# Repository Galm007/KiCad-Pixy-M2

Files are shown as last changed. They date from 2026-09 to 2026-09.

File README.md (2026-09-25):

# Pixy-M2 — Micromouse Controller PCB

A single-board controller for a micromouse robot. The board carries an
**ESP32-S3** module, two **DRV8231A** motor drivers with current regulation,
a **2S LiPo** power path with fusing, switching and UVLO, a **3.3 V buck**,
and connectors for four **VL53L0X** time-of-flight wall sensors, a **BNO085**
IMU and two **Pololu N20** gearmotors with encoders.

Designed in **KiCad 10**. 4-layer, 66 × 100 mm, fully placed and routed.

<p align="center">
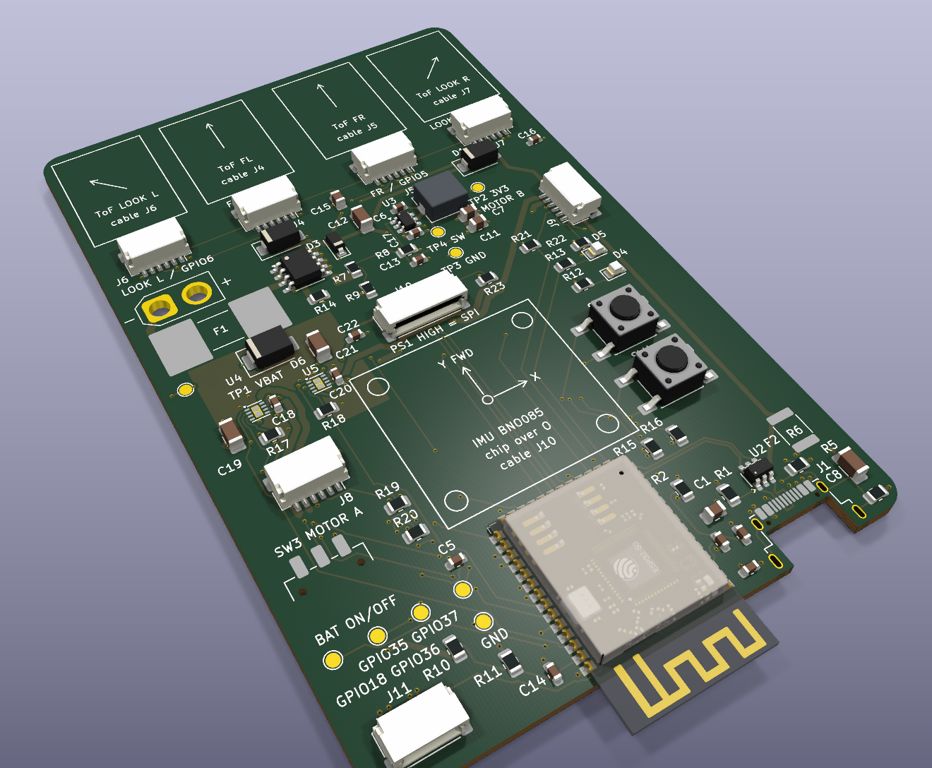
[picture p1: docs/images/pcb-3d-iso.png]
Pixy-M2 3D render, isometric view
  
</p>

| | |
|---|---|
| **MCU** | ESP32-S3-WROOM-1-**N16** (16 MB flash, no PSRAM), Wi-Fi/BLE, native USB |
| **Power in** | 2S LiPo (7.4 V nominal, 8.4 V full) via XT30, or USB-C 5 V |
| **Logic rail** | 3.3 V, AP63203 2 A synchronous buck |
| **Motor drive** | 2 × TI DRV8231A H-bridge, 1.00 A hardware current limit, per-motor current sense into the ADC |
| **Sensors** | 4 × VL53L0X ToF (I²C), BNO085 9-DoF IMU (SPI), 2 × 12 CPR quadrature encoders |
| **Protection** | 1500 A-breaking battery fuse, USB PPTC, 600 W TVS on the motor rail, USB ESD array, hardware UVLO |
| **PCB** | 66 × 100 mm, 4 layers, 1.6 mm, 78 footprints, 253 vias, ~2.4 m of track |
| **Status** | Schematic complete, ERC 0/0. Layout routed, DRC 0 violations / 0 unconnected / 0 parity. **Not yet fabricated.** |

---

## Contents

- [Board renders](#board-renders)
- [Schematic](#schematic)
- [System architecture](#system-architecture)
- [Design decisions](#design-decisions)
- [Pin and connector reference](#pin-and-connector-reference)
- [PCB layout](#pcb-layout)
- [Parts list](#parts-list)
- [Repository layout](#repository-layout)
- [Working with the project](#working-with-the-project)
- [Bring-up notes for firmware](#bring-up-notes-for-firmware)
- [Status and open items](#status-and-open-items)
- [License](#license)

---

## Board renders

The top of each image is the **front** of the robot: the four ToF sensor
mounts face the maze walls ahead, and the ESP32-S3 antenna overhangs the rear
edge.

<table>
  <tr>
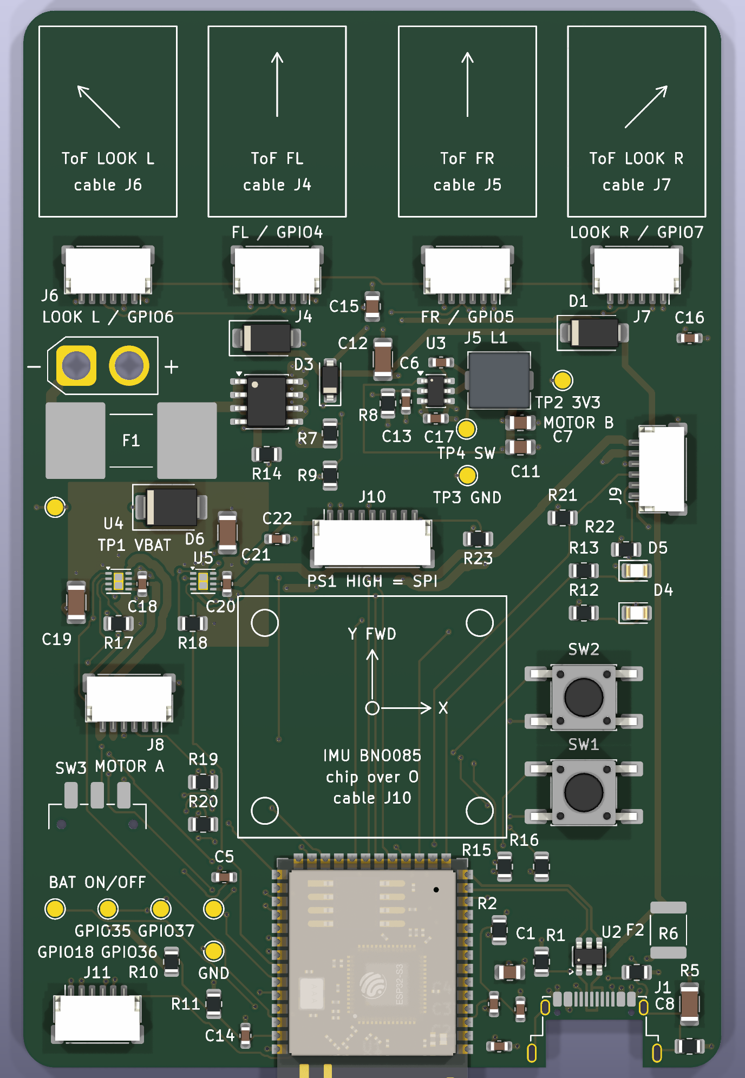
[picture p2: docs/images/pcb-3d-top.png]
Top side
    <td align="center"><br><b>Top</b></td>
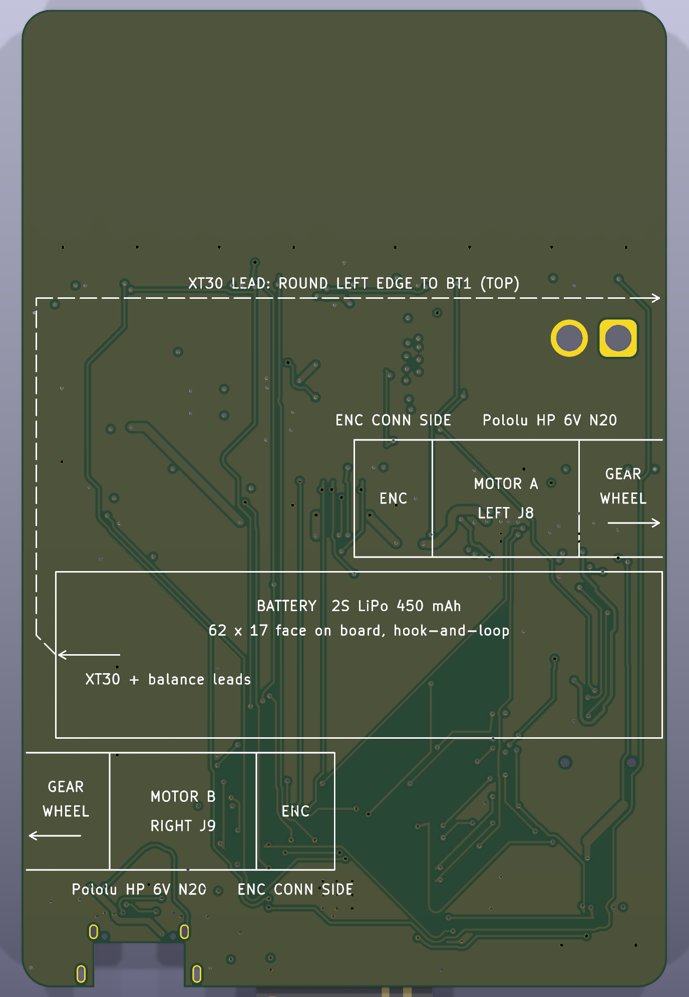
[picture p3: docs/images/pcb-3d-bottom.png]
Bottom side
    <td align="center"><br><b>Bottom</b> (mirrored)</td>
  </tr>
</table>

The silkscreen prints where each off-board part attaches:

- **Top:** the four ToF mounts with their aim arrows and the connector each
  cable plugs into, and the BNO085 breakout outline centred on the robot's
  rotation centre.
- **Bottom:** the two Pololu HP 6V gearmotors, with the gearbox face on the
  board edge and the shaft on the wheel axle. `ENC CONN SIDE` marks the face
  their encoder boards stand proud of, which must point outboard. Between the
  motors is the 2S battery's outline, with an arrow at the end its leads
  leave from and a dashed line for the lead's route round the left edge to
  BT1.

---

## Schematic

Single flat A3 sheet: [`Pixy-M2.kicad_sch`](Pixy-M2.kicad_sch).

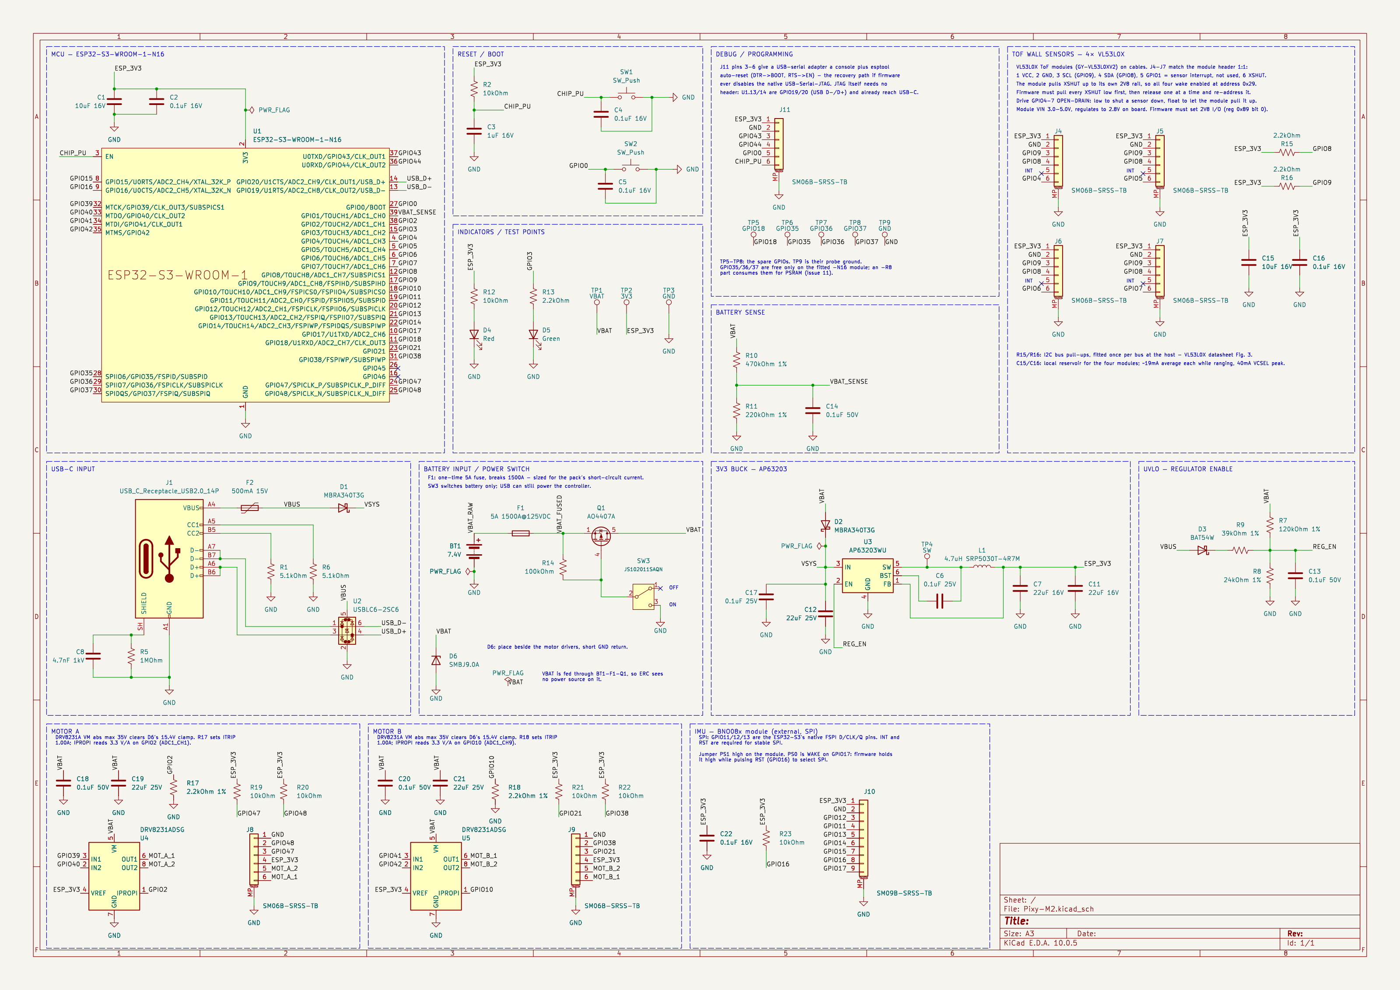
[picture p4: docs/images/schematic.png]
Schematic


---

## System architecture

```mermaid
flowchart LR
    BAT["2S LiPo<br/>XT30 (BT1)"] --> F1["F1<br/>5 A fuse<br/>1500 A break"]
    F1 --> Q1["Q1 P-FET<br/>switched by SW3"]
    Q1 -- VBAT --> DRV["U4 / U5<br/>DRV8231A ×2"]
    Q1 -- VBAT --> D6["D6 TVS<br/>SMBJ9.0A"]
    Q1 -- VBAT --> D2["D2<br/>Schottky"]
    USB["USB-C (J1)"] --> F2["F2<br/>500 mA PPTC"]
    F2 -- VBUS --> D1["D1<br/>Schottky"]
    D1 -- VSYS --> BUCK["U3 AP63203<br/>3.3 V buck"]
    D2 -- VSYS --> BUCK
    BUCK -- ESP_3V3 --> MCU["U1<br/>ESP32-S3"]
    BUCK -- ESP_3V3 --> PERIPH["ToF ×4, IMU,<br/>encoders"]
    DRV --> MOT["J8 / J9<br/>N20 motors + encoders"]
    MCU <-->|I²C| TOF["J4–J7<br/>VL53L0X ×4"]
    MCU <-->|SPI| IMU["J10<br/>BNO085"]
    MCU <-->|USB D±| USB
```

### Power path

```
 BT1+ ── F1 ── VBAT_FUSED ── Q1 (S→D) ── VBAT ──┬── D2 ──┐
                   │            │                ├── U4/U5 motor drivers
                  R14           G                ├── R7/R8 UVLO divider
                   └────────────┤                ├── R10/R11 battery sense
                           SW3 (gate only)       └── D6 TVS to GND
                                                          ├── VSYS ── U3 buck ── ESP_3V3
 J1 VBUS ── F2 ── VBUS ── D1 ─────────────────────────────┘
                   ├── D3/R9 USB enable path
                   └── U2 ESD clamp reference
```

- **`VBAT`** is the switched, fused motor rail. Motor current does **not** pass
  through D2. D2 feeds only the buck input.
- **`VSYS`** is the diode-OR of battery and USB. It reaches **~8.1 V** on a
  full pack.
- **`ESP_3V3`** feeds the module, the four ToF sensors, the IMU, the encoders,
  the LEDs and the drivers' `VREF` pins.
- **USB alone runs the controller** with SW3 off. That makes bench work and
  flashing possible without a pack. There is no on-board charger; charge the
  pack separately.

---

## Design decisions

The full reasoning, including rejected alternatives and the measurements behind
each change, lives in [`CLAUDE.md`](CLAUDE.md). This section covers the main
choices.

### One board, no daughterboard

An earlier version put the motors, drivers and IMU on a daughterboard that
mated through two 22-pin headers. Those headers were the heaviest and tallest
parts after the module, and they carried motor return current through eight
ground pins. The design now puts everything on one 4-layer board. Motor
return current flows in a solid ground plane, and the robot loses the mass and
height of the headers. The headers were deleted only once every GPIO they
carried ended on a real part.

### Motor driver: TI DRV8231A

The driver has to survive what the TVS lets through, not just the 8.4 V pack.
D6 clamps `VBAT` at up to **15.4 V**, and that ruled out the usual micromouse
parts:

| Part | VM abs max | Verdict |
|---|---:|---|
| DRV8833 | 11.8 V | below the clamp: rejected |
| TB6612FNG | 15.0 V | below the clamp: rejected |
| DRV8874 / DRV8876 | 40 V | good, but no stock KiCad symbol |
| **DRV8231A** | **35 V** | **fitted**, 2.3× the clamp |

The DRV8231A also:

- runs down to **4.5 V**, which covers the whole usable pack range;
- has **internal 100 kΩ pulldowns on IN1/IN2**, so both motors stay off while
  the ESP32's GPIOs float at reset;
- needs no nSLEEP or nFAULT pin, which saves GPIOs;
- has **integrated current regulation and an `IPROPI` sense output**.

### Current limit: 1.00 A, set by the connector

```
ITRIP = VREF / (AIPROPI × RIPROPI) = 3.3 V / (1500 µA/A × 2.2 kΩ) = 1.00 A
```

J8/J9 use JST SH connectors so Pololu's own encoder cable plugs in 1:1. SH
contacts and that cable are rated **1 A**, so R17/R18 hold the limit there.
The limit still gives ~63 % of the motor's 6 V stall torque. It also bounds the
driver's dissipation: an unregulated stall at 8.4 V would draw ~1.9 A and put
the 2 × 2 mm WSON into thermal shutdown. `IPROPI` reads 3.3 V/A on an ADC1 pin
for each motor, so firmware can detect a stall and cut drive long before the
fuse matters.

### Battery fuse: one-time, 1500 A breaking

The chosen pack is a 2S 450 mAh 100C LiPo. Its estimated dead-short current is
**200–400 A**. The original 3 A PPTC could only break 40 A, so it was replaced
with a **Littelfuse 0885005.DR**: 5 A fast-acting, 1500 A breaking at
125 VDC. Normal worst-case load is ~2.4 A: both motors at the limit plus the
buck. Slow overload protection is now the job of the driver current limit and
firmware stall detection. F1 only opens on a real fault.

### Hardware undervoltage lockout

The buck's `EN` pin has a built-in comparator with switched hysteresis. A 1 %
divider (R7/R8) on `VBAT` sets it to:

| | Pack voltage | Per cell |
|---|---:|---:|
| Turn on | 6.90 V | 3.45 V |
| Turn off | 5.94 V | 2.97 V |

A second path from `VBUS` (D3 + R9) holds `EN` high on USB alone, so the board
runs with no pack fitted. D3 is required. Without it, R9 becomes a pull-down
whenever a USB cable from an unpowered host is plugged in, and the board will
not start on battery. Firmware still does the accurate low-voltage cutoff; the
hardware UVLO is the backstop for when firmware is not running.

### Battery sense without a gate FET

`VBAT` → 470 kΩ / 220 kΩ → GPIO1 (ADC1_CH0), with a 100 nF reservoir cap.

- The divider draws 12 µA, well under the 58 µA of the UVLO divider, which
  cannot be gated. A gate FET would save almost nothing.
- A low-side gate would have been harmful: the sense node floats up into the
  GPIO clamp.
- A full-pack reading sits at 2.68 V. Even a badly overcharged 9.5 V pack reads
  3.03 V, still inside the ADC's range.
- Both dividers are downstream of Q1, so SW3 OFF removes their drain on the
  pack.

### Buck converter

- The **AP63203WU** is a fixed 3.3 V part, so it needs no feedback divider.
- **L1 is a Bourns SRP5030T-4R7M** (Isat 6 A, 53 mΩ). It replaced an 0805
  inductor that would have saturated at a few hundred mA.
- **C17 straddles the package under U3**, across IN and GND, which is the
  tightest input loop the pinout allows. C12 (22 µF 25 V 1206) is the bulk. It
  keeps ~11–13 µF at 8.4 V bias, which meets the datasheet's 10 µF effective
  input capacitance.
- **The switch node is 3.57 mm² of top copper with no vias.** TP4 hangs off it
  as a short stub.

### OR-ing diodes

D1 and D2 are the same **onsemi MBRA340T3G** (40 V, 3 A, SMA). D2 carries
only the buck's input, ~0.43 A worst case, so an ideal-diode controller is not
worth it. The 40 V rating covers the 15.4 V TVS clamp reaching `VSYS`.

### IMU on SPI, not I²C

The BNO085 could have shared the ToF I²C bus on throughput alone. It was put
on its own SPI bus for **latency**: an IMU interrupt that arrives mid-way
through a ToF read would wait up to ~150 µs, which is 15 % of a 1 kHz control
period. SCK, MOSI and MISO are on the ESP32-S3's native FSPI pins, so they go
through the IO MUX rather than the GPIO matrix. INT and RST are wired because
the BNO08x needs both for stable SPI. WAKE shares a pin with PS0 on the module.

### Four ToF sensors on one I²C bus

Every VL53L0X powers up at address `0x29`, and the address is volatile. Each
sensor therefore gets its own XSHUT line (GPIO4–7), so firmware can release the
sensors one at a time and re-address them. R15/R16 (2.2 kΩ) are the only bus
pull-ups, placed near the host, as the datasheet recommends. J4–J7 use the
GY-VL53L0XV2 module's own header order, so the cable is a straight 1:1 loom.

### USB

- **Series resistors deleted.** The ESP32-S3 PHY is impedance-matched, and the
  extra pads would have broken the differential pair beside the connector.
- **U2 (USBLC6-2SC6) is turned 90°** so its flow-through pins face J1 and U1.
  The pair then runs J1 → U2 → U1 entirely on the top layer with no vias.
- **Pair geometry is 0.25 mm trace / 0.15 mm gap.** A 2-D field solver
  ([`tools/impedance/zdiff.py`](tools/impedance/zdiff.py)) gives 88–94 Ω on a
  JLC04161H-7628 stackup.
- **No JTAG header.** The built-in USB-Serial-JTAG over USB-C already provides
  flashing, console and debugging.

### Strapping pins

GPIO45 and GPIO46 carry explicit no-connect flags. Driving GPIO45 high at reset
sets the flash rail to 1.8 V and the board will not boot. GPIO46 high with
GPIO0 low is an invalid boot combination. GPIO3 is the safe one of the three,
and drives the green status LED active-high, so its reset state stays low.

### Capacitor ratings

Every capacitor's voltage rating is in its Value field, so it shows on the
schematic. Two are worth pointing out:

- **C8** (USB shield) is **4.7 nF 1 kV in 1206**. An 8 kV ESD contact
  discharge puts ~250 V across it.
- **C19/C21** (motor bulk) are **22 µF 25 V** because of the 15.4 V TVS clamp.

---

## Pin and connector reference

### GPIO allocation

All 23 GPIOs left free after the core functions are used; four are spares on
test pads.

| Function | GPIO |
|---|---|
| USB D− / D+ | 19 / 20 |
| Boot button (SW2), also J11 | 0 |
| Battery sense (ADC1_CH0) | 1 |
| Status LED (green, active high) | 3 |
| ToF XSHUT 1–4 (J4–J7) | 4, 5, 6, 7 |
| I²C SDA / SCL (ToF bus) | 8 / 9 |
| Motor A IN1 / IN2 | 39 / 40 |
| Motor B IN1 / IN2 | 41 / 42 |
| Motor A / B current sense (IPROPI, ADC1) | 2 / 10 |
| Encoder A: OUT A / OUT B | 47 / 48 |
| Encoder B: OUT A / OUT B | 21 / 38 |
| IMU SPI SCK / MOSI / MISO / CS | 12 / 11 / 13 / 14 |
| IMU INT / RST / WAKE (PS0) | 15 / 16 / 17 |
| Debug UART0 TX / RX (J11) | 43 / 44 |
| Spare, on TP5–TP8 | 18, 35, 36, 37 |
| Strapping, deliberately no-connect | 45, 46 |

### Connectors

All the signal connectors are **JST SH 1.0 mm side-entry**.

**J4–J7: VL53L0X ToF sensors** (`SM06B-SRSS-TB`, GY-VL53L0XV2 header order)

| Pin | 1 | 2 | 3 | 4 | 5 | 6 |
|---|---|---|---|---|---|---|
| Signal | **VCC 3.3 V** | GND | SCL | SDA | INT (NC) | XSHUT |

> ⚠️ Pin 1 is **VCC**, not GND. A cable built "the usual way round" puts
> 3.3 V on the sensor's ground.

| Connector | Position | XSHUT |
|---|---|---|
| J4 | Front left (FL) | GPIO4 |
| J5 | Front right (FR) | GPIO5 |
| J6 | Look-ahead left, 45° | GPIO6 |
| J7 | Look-ahead right, 45° | GPIO7 |

**J8 / J9: motor + encoder** (`SM06B-SRSS-TB`, Pololu 12 CPR encoder order)

| Pin | 1 | 2 | 3 | 4 | 5 | 6 | MP |
|---|---|---|---|---|---|---|---|
| Signal | GND | OUT B | OUT A | VCC 3.3 V | M2 | M1 | GND |
| Pololu wire | green | white | yellow | blue | black | red | — |

J8 is motor A (left) and J9 is motor B (right). Use Pololu's straight SH–SH
encoder cable (#4765–#4769). R19–R22 pull the encoder outputs up to 3.3 V.

**J10: BNO085 IMU** (`SM09B-SRSS-TB`)

| Pin | 1 | 2 | 3 | 4 | 5 | 6 | 7 | 8 | 9 |
|---|---|---|---|---|---|---|---|---|---|
| Signal | VIN 3.3 V | GND | SCK | MOSI | MISO | CS | INT | RST | WAKE / PS0 |

> ⚠️ Jumper **PS1 high** on the module. Stock BNO08x breakouts ship in I²C mode
> and will not answer on SPI until it is changed.

**J11: debug / recovery** (`SM06B-SRSS-TB`)

| Pin | 1 | 2 | 3 | 4 | 5 | 6 |
|---|---|---|---|---|---|---|
| Signal | 3V3 (reference only) | GND | U0TXD | U0RXD | GPIO0 (BOOT) | CHIP_PU (EN) |

Pins 3–6 are an esptool auto-reset interface for a USB-UART adapter: DTR →
BOOT, RTS → EN. It is the way back in if firmware ever disables the native USB.

**Other**

| Ref | Part | Purpose |
|---|---|---|
| J1 | Amphenol 12401948E412A USB-C | Power, flashing, console, JTAG |
| BT1 | XT30U-M | 2S LiPo input |
| SW1 / SW2 | Tactile | Reset / Boot |
| SW3 | C&K JS102011SAQN slide | Battery ON/OFF (gate control only) |
| D4 / D5 | Red / green LED | Power (always on) / status (GPIO3) |
| TP1–TP4 | Test pads | VBAT, 3V3, GND, SW node |
| TP5–TP9 | Test pads | Spare GPIO18/35/36/37, probe GND |

---

## PCB layout

### Stackup

4 layers, 1.6 mm, designed for **JLC04161H-7628** (~0.2 mm L1–L2 prepreg).

| Layer | Use |
|---|---|
| **L1** F.Cu | Components, USB pair, buck switch node, motor-driver power loops, ground pour around the motor region |
| **L2** In1.Cu | **Solid, unbroken GND plane.** No signals, no splits. |
| **L3** In2.Cu | `ESP_3V3` pour plus a separate `VBAT` island under the motor region |
| **L4** B.Cu | Secondary routing plus a GND pour stitched to L2 |

The ground plane is never split. Noise is controlled by **placement**
instead. The motor drivers, the bulk capacitors, D6 and the battery entry
share the left-hand region. The MCU, ADC nodes and I²C sit away from it.

<p align="center">
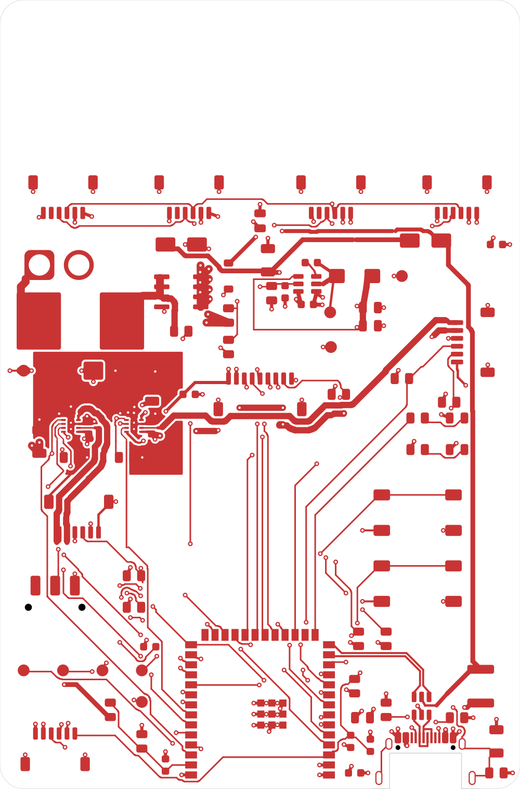
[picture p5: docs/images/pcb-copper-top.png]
Top copper layer
  <br>
  <em>Top copper (F.Cu). The 0.8 mm motor trunks, the 1.0 mm battery path and the motor-region ground pour are on the left.</em>
</p>

### Layout highlights

- **Motor outputs** are 0.8 mm trunks. The only narrower copper is inside
  each driver's own pin field, and a custom DRC rule enforces that. Each pair
  runs together to its connector: the loop areas are **23.9 mm²** (A) and
  **9.8 mm²** (B).
- **Driver thermal pads** each have two filled-and-capped in-pad vias
  (IPC-4761 type VII) plus four more nearby. Only two fit a 0.9 × 1.6 mm pad
  under the hole-to-hole rule.
- **VM bypass caps** sit 1.33 mm from each driver's VM pin, across VM and GND.
  The loop closes in top copper with no plane hop.
- **Antenna keep-out**: the module's antenna overhangs the rear edge, with an
  all-layer copper keep-out defined as a board rule area.
- **Rules are encoded, not just followed.** Netclasses and
  [`Pixy-M2.kicad_dru`](Pixy-M2.kicad_dru) enforce:
  - motor trunk width;
  - USB width, layer and coupling;
  - power and battery path widths;
  - a 0.2 mm signal floor;
  - clearance floors keeping `REG_EN`, `VBAT_SENSE` and the IPROPI lines away
    from motor and switching copper.

  Each rule was tested by breaking a copy of the board and checking that DRC
  fired.

The board was routed by a purpose-written A* grid router
([`tools/autoroute/`](tools/autoroute/)) and then reworked in stages, each
driven by a design review. Every stage is scripted and reproducible. The review
findings and the evidence for each fix (DRC reports, measurements,
before/after images) are under [`layout/`](layout/).

---

## Parts list

Parts for **one robot**, taken from **[`BOM.md`](BOM.md)**. BOM.md also has
each part's status, the cable wiring, the mechanical parts and the tools. The
shopping list below has one line per part to buy.

### Shopping list

Quantities are exact, with no spares except the crimp contacts. Where BOM.md
lets one part fill several positions, the list merges them: one 0.1 µF 50 V
part covers all eleven 0.1 µF positions, and every resistor is bought at 1 %.
R7–R11 and R17/R18 must stay 1 %: they set the UVLO thresholds, the
battery-sense ratio and the motor current limit.

| Qty | Part | For |
|---:|---|---|
| 1 | Espressif **ESP32-S3-WROOM-1-N16** | U1. N16 only, not an `-R8` variant |
| 2 | TI **DRV8231ADSGR** | U4, U5 |
| 1 | Diodes Inc **AP63203WU-7** | U3. Fixed 3.3 V, not the AP63200 |
| 1 | ST **USBLC6-2SC6** | U2 |
| 1 | AOS **AO4407A** | Q1. Not the IRF7404 the symbol names |
| 2 | onsemi **MBRA340T3G** | D1, D2 |
| 1 | Vishay **BAT54W-E3-08** (SOD-123) | D3. Nexperia's BAT54W is SOT-323 and won't fit |
| 1 | Vishay **SMBJ9.0A-E3/52** | D6 |
| 1 | Red LED, high-efficiency, 0805 | D4. Must be visibly lit at ~150 µA |
| 1 | Green LED, 0805 | D5 |
| 1 | Bourns **SRP5030T-4R7M** | L1 |
| 1 | Littelfuse **0885005.DR** | F1 |
| 1 | Bourns **MF-MSMF050-2** | F2 |
| 1 | C&K **JS102011SAQN** | SW3 |
| 2 | E-Switch **TL3301NF160QG** | SW1, SW2 |
| 1 | Amphenol **12401948E412A** | J1 |
| 1 | AMASS **XT30U-M** | BT1 |
| 7 | JST **SM06B-SRSS-TB(LF)(SN)** | J4–J9, J11 |
| 1 | JST **SM09B-SRSS-TB(LF)(SN)** | J10 |
| 11 | 0.1 µF 50 V X7R, 0603 | C2, C4–C6, C13, C14, C16–C18, C20, C22 |
| 1 | 1 µF 16 V X7R, 0603 | C3 |
| 2 | 10 µF 16 V X5R/X7R, 0805 | C1, C15 |
| 2 | 22 µF 16 V X5R/X7R, 0805 | C7, C11 |
| 3 | 22 µF 25 V X5R/X7R, 1206 | C12, C19, C21 |
| 1 | 4.7 nF 1 kV, 1206 | C8 |
| 7 | 10 kΩ 1 %, 0805 | R2, R12, R19–R23 |
| 5 | 2.2 kΩ 1 %, 0805 | R13, R15–R18 |
| 2 | 5.1 kΩ 1 %, 0805 | R1, R6 |
| 1 | 24 kΩ 1 %, 0805 | R8 |
| 1 | 39 kΩ 1 %, 0805 | R9 |
| 1 | 100 kΩ 1 %, 0805 | R14 |
| 1 | 120 kΩ 1 %, 0805 | R7 |
| 1 | 220 kΩ 1 %, 0805 | R11 |
| 1 | 470 kΩ 1 %, 0805 | R10 |
| 1 | 1 MΩ 1 %, 0805 | R5 |
| 1 | 4-layer PCB, 1.6 mm, 66 × 100 mm | Order with the [fabrication options](#pcb-fabrication-options) below |
| 1 | SMT stencil | Optional, but hard to do without for the WSON parts |
| 4 | **GY-VL53L0XV2** ToF module (`HW-842`) | Wall sensors on J4–J7 |
| 1 | Adafruit **BNO085** breakout, #4754 | IMU on J10 |
| 2 | Pololu **Micro Metal Gearmotor HP 6V with 12 CPR encoder** (#5153–#5165) | J8, J9. Gear ratio not chosen yet; use the same for both |
| 2 | Pololu **JST SH encoder cable**, female–female (#4765–#4769, 10–63 cm) | Motors to J8, J9 |
| 1 | OVONIC **2S 450 mAh 100C LiPo, XT30** | BT1. The Amazon listing (B0D2KT723L) is a 4-pack |
| 5 | JST **SHR-06V-S-B** housing | Four ToF cables and the optional debug lead |
| 1 | JST **SHR-09V-S-B** housing | IMU cable |
| ~80 | JST **SSH-003T-P0.2-H** crimp contact | 39 are used; hand crimping wastes some |
| — | 28–32 AWG wire | ToF, IMU and debug cables |

Not listed here:

- **Mechanical parts.** Wheels, motor brackets, drivetrain and sensor brackets
  are not designed yet.
- **Tools.** A 2S balance charger (XT30, JST-XH), a JST SH crimp tool, solder
  paste with hot air or reflow, and a 3.3 V USB-UART adapter for J11.

Both are in BOM.md, sections E and F.

### PCB fabrication options

- 4-layer, 1.6 mm, JLC04161H-7628 or equivalent.
- **Impedance control** on USB D+/D− (90 Ω differential), or confirm the
  geometry with the fab's calculator.
- **Via fill and cap (IPC-4761 type VII)** for the four thermal vias under
  U4/U5. The requirement is noted on `Dwgs.User`. Tenting is not a substitute.

---

## Repository layout

```
Pixy-M2.kicad_pro / .kicad_sch / .kicad_pcb   KiCad 10 project
Pixy-M2.kicad_dru                             custom DRC rules
Pixy-M2.pretty/                               project footprint library (U1 with antenna overhang)
fp-lib-table                                  registers the project library
BOM.md                                        full bill of materials
CLAUDE.md                                     full design notes: every decision, issue and measurement
REVIEW.md                                     layout design review
docs/images/                                  renders used in this README
layout/                                       placement notes, review evidence, DRC/ERC reports per fix
tools/autoroute/                              the grid router and scripted rework stages
tools/impedance/zdiff.py                      2-D field solver for the USB differential pair
DS_vl53l0x.pdf                                VL53L0X datasheet
```

`USB_C_Receptacle_Amazon.kicad_mod` in the root is **not used** by the board.
J1 uses the stock `Connector_USB:USB_C_Receptacle_Amphenol_12401948E412A`.

---

## Working with the project

Open `Pixy-M2.kicad_pro` in **KiCad 10**. The project library `Pixy-M2.pretty`
is registered through `fp-lib-table`. The Espressif footprint library
(`PCM_Espressif`) is only needed if you want to compare U1 against the stock
footprint.

### Checks

```sh
# Electrical rules
kicad-cli sch erc -o erc.rpt Pixy-M2.kicad_sch

# Design rules, with zone refill and schematic parity
kicad-cli pcb drc --schematic-parity --refill-zones --format json -o drc.json Pixy-M2.kicad_pcb

# Netlist, to diff after any schematic edit
kicad-cli sch export netlist --format kicadsexpr -o after.net Pixy-M2.kicad_sch
```

Current results: **ERC 0 errors / 0 warnings; DRC 0 violations, 0 unconnected
items, 0 schematic-parity issues.**

Always refill zones before DRC. Without a refill, every plane-connected pad
shows up as unconnected.

### Things that will silently break the design

- **Do not "Update Symbols from Library" on U4/U5.** The stock
  `Driver_Motor:DRV8231ADSG` symbol types OUT2 as `power_in`. The copy cached in
  this schematic fixes it to `output`. Updating reverts the fix and brings back
  two ERC errors.
- **Do not "Update Footprint from Library" on U1** back to `PCM_Espressif`.
  That restores antenna silkscreen that prints off the board edge.
- **Do not rotate U2 back** without re-routing the USB pair.
- **Keep "Signal minimum width" as the first rule in `Pixy-M2.kicad_dru`.**
  When two rules set the same constraint, the later one wins. Moving this rule
  below the motor, USB or power rules relaxes them to 0.2 mm.
- **Close KiCad before editing the files on disk.** A `~Pixy-M2.*.lck` file
  means the GUI has the project open, and whichever side saves last wins.

### Generating fabrication files

Gerbers, drill files and placement files are generated outputs and are
git-ignored. Export them from the PCB editor, or run:

```sh
kicad-cli pcb export gerbers -o gerbers/ Pixy-M2.kicad_pcb
kicad-cli pcb export drill   -o gerbers/ Pixy-M2.kicad_pcb
kicad-cli pcb export pos     -o gerbers/Pixy-M2-pos.csv Pixy-M2.kicad_pcb
```

---

## Bring-up notes for firmware

- **ToF sensors all wake at `0x29`.** GPIO4–7 float at reset and the modules
  pull XSHUT up, so all four sensors come up enabled at once. Firmware should
  first **drive all four XSHUT lines low**, then release one at a time and
  write a new address to register `0x8A`. The addresses are lost at every
  power cycle.
- **Drive XSHUT open-drain** (`GPIO_MODE_OUTPUT_OD`), not push-pull. The
  module's XSHUT sits on a 2.8 V rail.
- **Leave the VL53L0X driver's 2V8 I/O mode on.** It is the default in both ST's
  API and Pololu's library.
- **Motors sleep when IN1 = IN2 = 0.** The drivers' internal pulldowns keep
  them off until firmware drives the pins.
- **Cap motor PWM at ~71 % duty.** The N20s are 6 V motors on an 8.4 V pack;
  71 % gives a 6 V equivalent on a full pack.
- **Use IPROPI for stall detection** (GPIO2 / GPIO10, 3.3 V/A). The ADC clips
  at ~0.94 A, just under the 1.00 A limit, so a stall reads as full scale.
- **Battery sense:** use `ADC_ATTEN_DB_12`. Scale by 690/220 and calibrate once
  against a meter reading at TP1. Allow ~50 ms after a step change (15 ms RC),
  and average over whole PWM periods.
- **With USB connected, the hardware UVLO is bypassed.** Firmware must cut off
  a low pack itself in that case.
- **Keep ADC reads on ADC1.** Every analog input already is, because ADC2 is
  unusable while Wi-Fi is active.
- **Status LED:** drive GPIO3 **high** to light it.

---

## Status and open items

**Done:** schematic, placement, routing, the design-review rework, the DRC
rule set and the silkscreen assembly marks. The last unmet layout rule, R8 and
C13 beside U3's EN pin, was closed on 2026-09-24
([`layout/reg-en/`](layout/reg-en/README.md)). No `REG_EN` copper is under U3
any more. Its closest approach to the switch node is now U3's own 0.95 mm pin
gap; it was 0.40 mm.

**Open before or during first fabrication:**

- [ ] **Mechanical design.** The drivetrain, wheel mounts and sensor brackets
      are not designed. The PCB has **no mounting holes** yet. The battery
      goes across the underside between the motors (2026-09-24), so the motor
      brackets may only fasten on the motors' outboard sides. The pack's lead
      needs about 13 cm to reach BT1; see `BOM.md`, "Battery".
- [ ] **Motor gear ratio.** Pick one for both motors. 12 CPR before gearing is
      low, so check that the ratio gives enough encoder edges for the control
      loop.
- [ ] **Current budget on real hardware.** Measure F1 temperature and U4/U5
      thermals during hard acceleration and stalls.
- [ ] **USB impedance.** Confirm 0.25 / 0.15 mm with the fab's calculator, or
      order impedance control.
- [ ] **IPROPI traces** pass 0.53 mm from motor copper. Validate on hardware.
- [ ] **Antenna performance** with the battery, motors and brackets fitted.

See [`CLAUDE.md`](CLAUDE.md) for each item's history and the reasoning behind
it.

---

## License

The design files, scripts and documentation in this repository are released
under the [MIT License](LICENSE).

Third-party material keeps its own terms:

- `DS_vl53l0x.pdf` is STMicroelectronics' datasheet, included for reference.
- `Pixy-M2.pretty/ESP32-S3-WROOM-1_AntennaOverhang.kicad_mod` is derived from
  Espressif's KiCad footprint library and remains under that library's license.

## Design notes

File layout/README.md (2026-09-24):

# Pixy-M2 initial placement — 2026-09-21

This is an **unrouted, provisional chassis layout**, not fabrication-ready mechanical design.

## Geometry and reservations

The PCB is 66 × 100 mm with R3 corners and a single closed perimeter. J1's stock mid-mount USB-C footprint requires a rear-edge notch; its Edge.Cuts geometry is integrated into the perimeter. There are no additional mounting holes or drivetrain cutouts. Existing connector locating holes remain part of their assigned footprints.

Coordinates in `placement.json` are millimetres from the board's front-left corner, +X right and +Y rear; the KiCad origin for this corner is (100, 60) mm. Angles follow KiCad footprint rotation conventions. The front is at the top of the preview.

| Reservation | Position relative to PCB front-left | Size / meaning |
|---|---|---|
| Complete width allowance | X = −12…78 | 90 mm including wheels, gears, brackets and cable protrusions |
| Side drive lanes | X = −12…0 and 66…78 | 12 mm each; illustrative 8 mm tire + 4 mm gear/clearance allocation |
| Wheel axes | Y = 50 and 82 | Ø30 mm wheels, 32 mm wheelbase |
| Left underside motor | X = 0…38, Y = 40…56 | 38 × 16 × 16 mm including encoder/cable allowance; shaft toward left. *Was Y = 44…60 until 2026-09-24: the 4 mm encoder allowance now faces outboard (forward)* |
| Right underside motor | X = 28…66, Y = 76…92 | 38 × 16 × 16 mm including encoder/cable allowance; shaft toward right. *Was Y = 72…88 until 2026-09-24: the allowance now faces outboard (rearward)* |
| Underside battery | X = 0.5…62.5, Y = 57.5…74.5, between the motors; rule area to X = 66 for the lead exit | 62 × 17 × 14 mm (OVONIC 2S 450 mAh, maker's envelope), wide face on the board, leads at the +X end. *Was X = 13…53, Y = 5…35 (40 × 30 × 15) until 2026-09-24* |
| Top-side IMU | X = 20.5…45.5, Y = 53.5…78.5 | 25 × 25 mm around nominal rotation centre (33, 66) |
| Four top sensor mounts | X = 1…15, 17…31, 35…49, 51…65; Y = 1…20 | 14 × 19 mm provisional mount/module envelope each |
| Antenna | Rear-centre; module reaches Y = 105.75 | Overhang, all-layer copper keepout and additional no-metal drawing |

`Dwgs.User` shows top reservations, drive lanes, wheels, axes, aim directions and dimensions. `User.1` shows underside body envelopes. `User.2` shows provisional attachment bands and RF clearance. These bands are reserved space, not final bolt patterns. *(2026-09-23: the ToF mounts, the IMU and both motors are now also printed on F.SilkS / B.SilkS by `tools/autoroute/assembly_marks.py`; see CLAUDE.md, "Assembly marks on the silkscreen".)*

**Battery bay, 2026-09-24** (`tools/autoroute/battery_bay.py`; CLAUDE.md, "Battery between the axles"). The pack now lies across the board between the two motors, with its centre on the rotation centre's Y. The motor envelopes are unchanged in size, but their 4 mm encoder allowance now faces outboard. Pololu's encoder board stands 3–4 mm proud of one face of the gearmotor, so each motor is mounted with that face outboard or toward the floor, never toward the battery. The inboard motor attachment bands and both battery strap bands are deleted. The pack is held on the board with hook-and-loop tape: no strap can pass the drive lanes beside it. Each outboard band moves 4 mm out with its envelope, to Y = 37…40 (left motor) and Y = 92…95 (right motor). The right one stops either side of J1 (X = 28…46.5 and 61.5…66). `User.2` also shows the lead route: from the pack's +X end, forward along X = 64.5, across the front strip at Y = 29.5, then round the left edge between J6 and BT1 to BT1 on top. That is about 13 cm of lead. B.SilkS prints the pack outline, its lead arrow and the route as a dashed line, and `ENC CONN SIDE` marks each motor's outboard face.

Board-level placement keepouts cover top modules and underside bodies. The antenna has a board-level all-layer copper keepout; the footprint also retains its original antenna rule area. The board-level antenna area permits U1 itself to overlap the area, while the footprint's own keepout protects against other footprints.

J4 = forward left / GPIO4, J5 = forward right / GPIO5, J6 = look-ahead left / GPIO6, J7 = look-ahead right / GPIO7. The latter two start at 45° outward, with 30–60° adjustment reserved. Rays show aiming adjustment, **not optical field of view**. The connectors face the sensor mounts; J10 faces the central IMU reservation.

## Electrical placement and verification

- All 78 schematic components, 66 exported nets, footprint assignments and schematic paths are preserved. Every footprint pad's net was compared against a fresh schematic netlist: zero mismatches.
- Zero tracks, vias or copper pours. Rule areas are not copper pours. Ratsnest connectivity is retained.
- All electronics are on F.Cu. All 22 existing drilled pads clear the underside body and attachment envelopes by their full pad bounds.
- No courtyard overlaps, pad shorts, malformed outline, placement-keepout violations or silkscreen collisions remain in DRC.
- Schematic parity: **zero issues**. DRC reports **220 expected unconnected items** for the unrouted board.
- The original project rules and four-layer/1.6 mm stackup are preserved; the schematic is unchanged.

## Five retained DRC findings

> **Resolved 2026-09-23** without changing the land patterns: see
> `layout/drc-clean/README.md`. J1's gap is allowed at JLCPCB's 0.20 mm by a rule
> scoped to J1's own pads and holes; U1's variant is now the project library
> footprint `Pixy-M2:ESP32-S3-WROOM-1_AntennaOverhang`.

1. **Four J1 pad-to-hole clearance errors:** the assigned stock Amphenol footprint has 0.25 mm between its locator holes and adjacent GND pads, versus the project's 0.30 mm minimum. These are intrinsic footprint geometry, not overlaps between placed components. Verify the connector drawing and fabricator capability before routing/fabrication; the rule has not been weakened and the findings have not been excluded. The original 0.20 mm board-edge clearance rule is satisfied.
2. **One U1 library-footprint mismatch warning:** antenna silkscreen segments crossing or crowding the rear edge were moved to F.Fab. Pads, electrical mapping, courtyard, antenna geometry and keepout remain unchanged. Updating this footprint from its library would restore those silkscreen segments.

`drc.json` contains the complete, unsuppressed report; `verification.json` records the net/mechanical checks.

## Mechanical limits before committing to hardware

The selected motor bracket, encoder protrusion, shafts, wheel hubs, gear mesh, fasteners, battery, sensor breakout and IMU dimensions must fit these allowances. In particular, the staggered motor shafts do not define a finished gear train: idlers, axle supports and gear ratios remain unspecified. Mount rigidity, PCB bending, screw access, ground clearance and actual wheel/gear tolerances need mechanical design validation. Top-side assemblies may lie above underside reservations because they occupy opposite sides; verify their real Z clearances and fastening method.

The 90 mm target gives 24 mm total nominal clearance in the stated 114 mm corridor. This does not prove diagonal transition clearance. The rigid module overhang brings the nominal component envelope to about 106 mm long before final brackets/cables; validate the complete swept shape and next-cell sensor visibility. Antenna performance also needs checking with the final battery, motors, gears and mounts installed.

## Previews

- `placement-preview.svg` / `.png`: dimensioned assembly overview, with actual top copper/silkscreen beneath the mechanical overlay.
- `top.svg` / `.png`: detailed top placement.
- `bottom.svg` / `.png`: mirrored bottom copper with underside and attachment reservations. Drawing-layer text is naturally mirrored in this bottom view.

No files are fabrication exports.

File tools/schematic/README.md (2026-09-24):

# schematic — the 2026-09-24 sheet re-layout

Re-arranged `Pixy-M2.kicad_sch` into framed functional blocks without changing
a single net, pin or part.

    python3 relayout.py OLD.kicad_sch OUT.kicad_sch   # one-shot, see below
    python3 netdiff.py before.net after.net           # exit 1 on any electrical change
    python3 blocks.py [sheet]                         # block extents on a sheet

- `schlib.py` reads the sheet span-preservingly: every item keeps KiCad's own
  text, and edits are coordinate rewrites, deletions or appended items.
- `clusters.py` groups items that touch by wire geometry. A cluster moved as a
  whole cannot lose a connection; clusters join each other only through labels.
- `relayout.py` phase 1 redraws two blocks (USB CC resistors off the D± pair;
  UVLO split from the buck on its existing `REG_EN` label). Phase 2 moves every
  cluster into its frame. It addresses items by UUID and old coordinates, so it
  only runs on the pre-re-layout sheet (`git show a0b645a:Pixy-M2.kicad_sch`).
- `netdiff.py` compares two `kicadsexpr` netlists: net names and members, and
  each part's value, footprint and fields.

Verified: 66 nets, 78 parts, 0 differences; ERC 0/0; PCB DRC with schematic
parity 0/0/0.

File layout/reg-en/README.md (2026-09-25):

# REG_EN beside U3.2 — 2026-09-24

The last open item in CLAUDE.md's "Layout constraints". `REG_EN` is a ~20 kΩ
node sitting 1.2 V above the AP63203's EN comparator threshold. The rule for
it was:

> Put R8 and C13 physically next to U3.2 and run the long leg from R7/R9 into
> them, not the reverse.

The issue-5 buck block did the reverse:

- **FB fenced U3's west side.** The dedicated FB sense trace left U3.1 west
  and ran down x = 136.6, 0.5 mm from the west pins, then round the south of
  the block to C11. EN had no way out on top copper.
- **So EN left through a via under the package.** The via sat between the
  pin columns, **0.40 mm from the SW pin**. Issue 8 measured that and set the
  DRC floor just under it, at 0.35 mm.
- **The filter parts were far away.** R8 was 7.35 mm of copper from U3.2,
  straddling the FB trace. C13 was 9.9 mm away, below it.

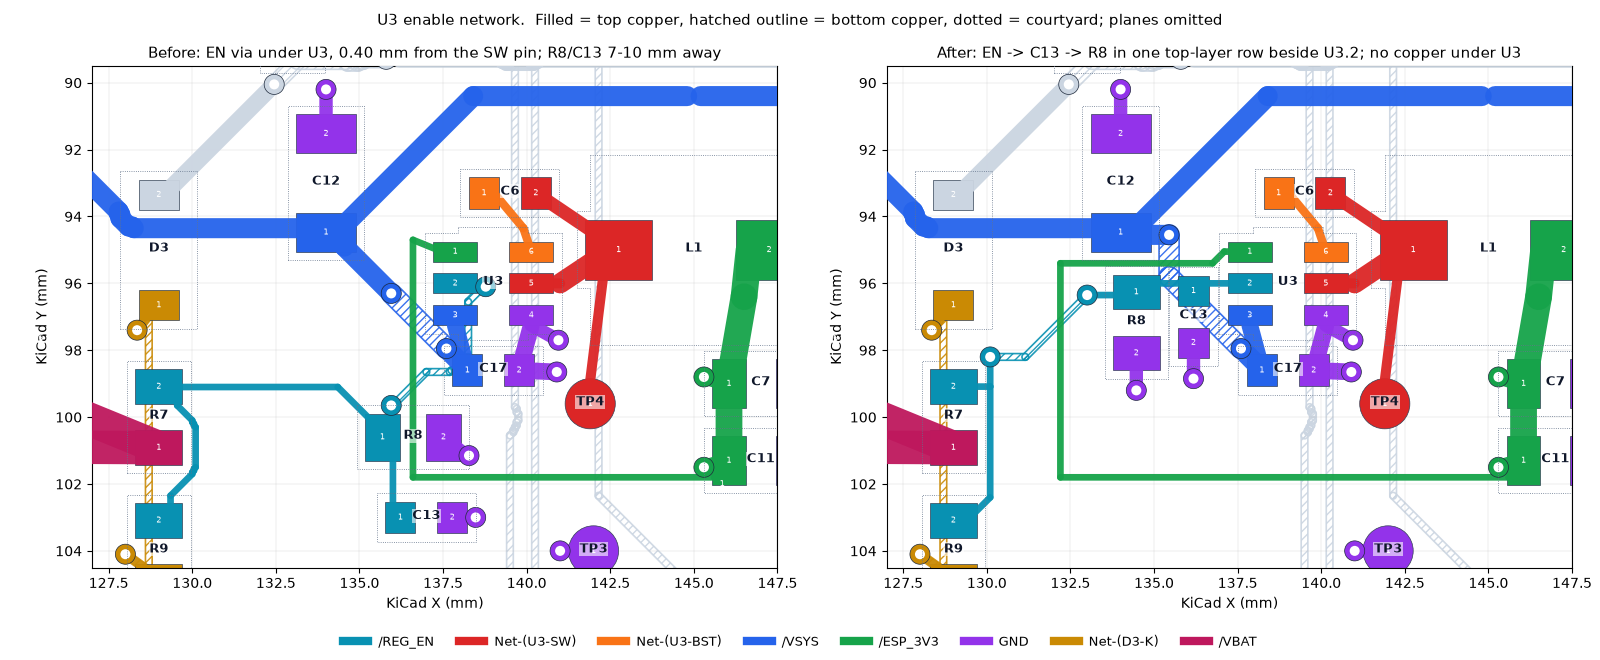
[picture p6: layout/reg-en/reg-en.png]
before and after


## What changed (`tools/autoroute/reg_en.py`)

The stage runs in `rework.py` after `battery_bay.py`. Standalone, it
converts an existing board once. It asserts every item it replaces, so a
board that has drifted fails rather than being half-edited.

- **C13 and R8 stand vertical in a row just west of U3.** C13 is at
  (136.18, 97.0) and R8 at (134.47, 97.175), both rot 270, so pad 1 (REG_EN)
  is to the north.
  - U3.2 → C13.1 → R8.1 is one straight top-layer run along y = 96, with
    the filter capacitor first.
  - Their GND pads face south, and each has its own plane via.
  - C13's courtyard is 0.04 mm clear of U3's. R8's is 0.2 mm clear of C12's.
- **FB keeps its dedicated, via-free top-layer route to C11.1.** It now
  leaves U3.1 along y = 95.4, between C12 and the new parts, and turns south
  at x = 132.2 instead of 136.6. The run along y = 101.8 to C11 is unchanged.
- **The long leg takes the vias.** It leaves R8.1 west and drops to B.Cu at
  (133.0, 96.35), inside FB's turn. It crosses under FB and comes up beside
  R7 at (130.1, 98.2), then runs down x = 130.1 to R7.2 and R9.2 as before.
  The nearer via is 5.65 mm from switching copper, C6's BST pad.
- **VSYS.** The C12 → C17 hop moves its upper via north of FB, to
  (135.45, 94.55). The lower via at (137.6, 97.95) and its C17 stub stay.

### Why FB did not go to B.Cu instead

That was the first layout tried. It is shorter (FB 16.6 mm), and it leaves
REG_EN with no via at all. It passed DRC.

**It was dropped because a via on FB bonds to the In2 3V3 pour beside U3.**
The pour connects to every via of its own net, so FB would have sensed the
plane next to the regulator. That is the plane pickup review finding 5
removed: "take a quiet feedback sense from the output-capacitor node".
Keeping the pour off those vias would need keepout rule areas on In2, which
nothing checks: delete one and FB silently re-bonds to the plane.

`REG_EN` belongs to no plane, so its vias tie nothing to In1 or In2. It takes
the crossing instead.

### Plane antipads

Every new via is at least 1.35 mm from any other non-plane via. Each via's
antipad is 1.1 mm across, and that spacing keeps a 0.25 mm web of plane
between them. In the B.Cu-FB attempt, the FB via sat 1.0 mm from the VSYS
via, and their antipads merged into one 2 mm void in In1.

In1 directly under U3 is now unbroken: the old EN via's antipad sat between
the pin columns.

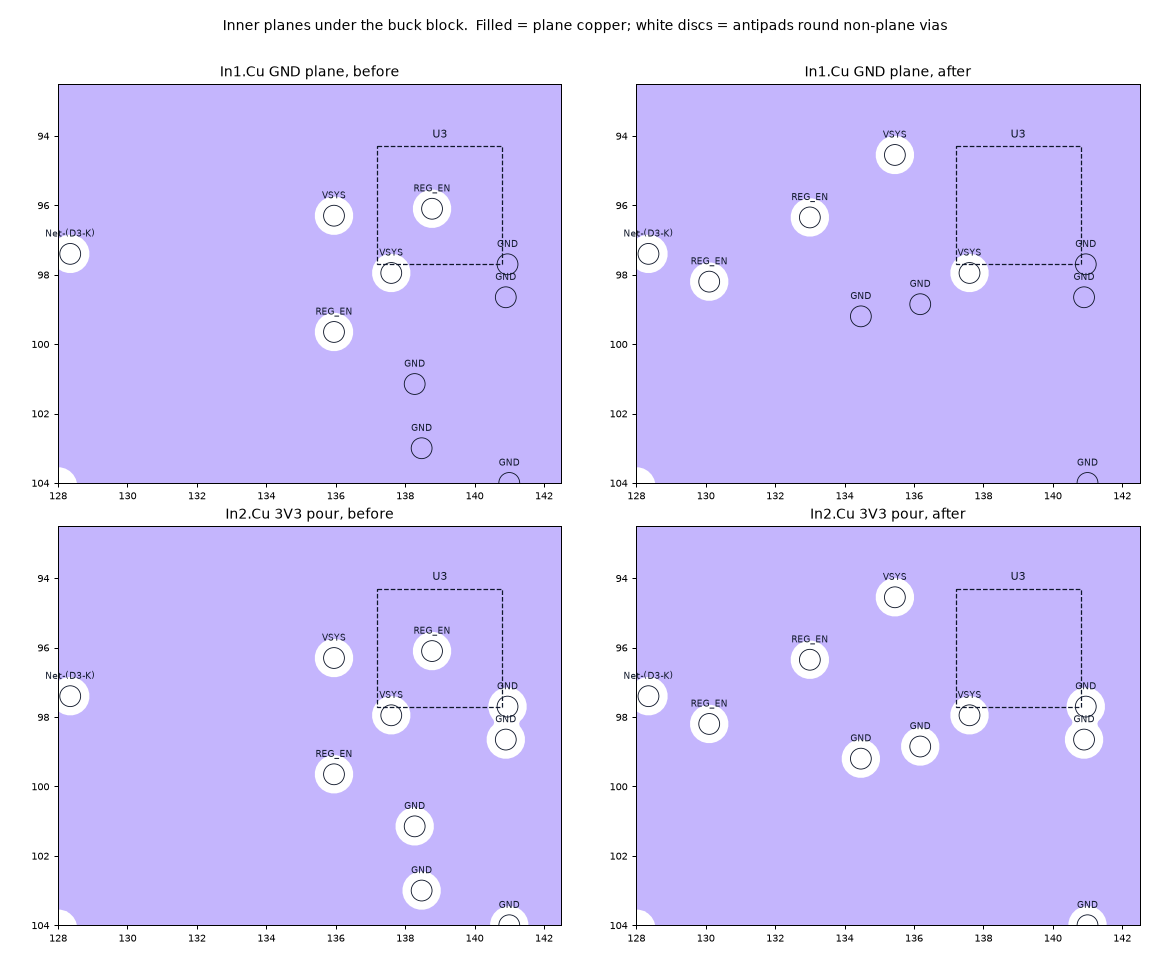
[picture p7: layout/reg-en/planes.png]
inner planes


## Measurements (`measure.py`, `measurements.json`)

    python3 layout/reg-en/measure.py BEFORE.kicad_pcb AFTER.kicad_pcb [--json OUT]

| | before | after |
|---|---:|---:|
| `REG_EN` to SW/BST, U3's own pad included (= DRC) | **0.40 mm** (EN via under U3) | **0.95 mm** (U3.2 to U3.5) |
| `REG_EN` copper outside U3.2 to SW/BST | 0.40 mm | **1.875 mm** |
| `REG_EN` vias inside U3's courtyard | 1 | **0** |
| copper path U3.2 → C13.1 | 9.90 mm | **1.91 mm** |
| copper path U3.2 → R8.1 | 7.35 mm | **3.66 mm** |
| copper path U3.2 → R7.2 / R9.2 | 14.72 / 19.70 mm | 10.87 / 14.43 mm |
| `REG_EN` track (F.Cu + B.Cu), vias | 12.30 + 5.39 mm, 2 | 10.65 + 3.67 mm, 2 |
| `REG_EN` vias, nearest gap to SW/BST | 0.40 mm | **5.65 mm** |
| FB path U3.1 → C11.1 | 18.10 mm, F.Cu only, 0 vias | 26.28 mm, F.Cu only, 0 vias |
| FB to SW/BST | 1.35 mm | 1.35 mm |
| VSYS C12.1 → C17.1 | 5.91 mm, 2 vias | 6.65 mm, 2 vias |
| vias on the board | 253 | 253 |

**0.95 mm is U3's own EN-to-SW pin gap.** A TSOT-23-6 puts EN and SW
opposite each other across the package, so no layout can do better. The
number the layout controls, the nearest REG_EN copper outside that pad, is
the EN stub's end inside U3.2 at 1.875 mm.

The two gap figures that include U3's pad reproduce `clearmin.py`'s DRC result
exactly, which is the cross-check on the script's geometry.

## Rule

"REG_EN clear of the switch node" in `Pixy-M2.kicad_dru` goes from
**0.35 mm to 0.9 mm**, just under the package's 0.95 mm. The issue-8 floor
sat below the intent, at whatever the board happened to achieve. This one
sits at the physical limit: any REG_EN copper put back under U3 fails it.
DRC still cannot check the placement half of the rule, R8/C13 beside U3.2;
that remains a review item.

## Validation

- **DRC** (`drc.json`): `--schematic-parity --refill-zones` gives 0
  violations, 0 unconnected, 0 parity issues, with the new floor in place.
  The schematic is unchanged.
- **Aperture audit** (`aperture-audit.json`): `via_openings.py` passes with
  253 vias and a 0.10 mm minimum ordinary gap.
- **Exact clearances** (`clearances.json`, `clearmin.py`): REG_EN-SW goes
  0.40 → 0.95 mm. Every other guarded pair is unchanged:
  - REG_EN to motor: 7.75 mm;
  - IPROPI to motor: 0.53 mm;
  - VBUS/VSYS to SW: 1.11 mm;
  - USB to other nets: 0.20 mm;
  - VBAT_SENSE: > 20 mm.
- **Negative tests** (`negative-tests.json`). The new floor fires:
  - on the board before this pass: the EN via at 0.40 mm, and the stub into
    it at 0.60 / 0.675 / 0.775 mm;
  - on a copy with a REG_EN track run 1.2 mm under U3 toward SW: 0.675 mm.
- **Nothing else moved.** A track/via diff against the previous board
  touches only `/REG_EN`, `/ESP_3V3` (the FB run), `/VSYS` and the two GND
  stitches of R8/C13. Three reference fields moved: R8, C13, and C17, whose
  upright label sat where C13 now is.
- **Replay.** A full `rework.py` run from `base-routed.kicad_pcb` reproduces
  the board. Every footprint, track, via and text is identical after refill.
  The only differences are the random member UUIDs of the five silkscreen
  groups, and one vertex of the B.Cu pour fill. The fill's area is identical,
  5214.121 mm².

## Correction

Issue 5 recorded that FB "never comes within 2.1 mm of SW or BST". Its run
to C11 along y = 101.8 passes TP4, the SW probe pad, at **1.35 mm**. DRC gives
that figure on the board before and after this pass, and the run is
untouched.

## Costs

- **FB is 8.2 mm longer**, 18.1 → 26.3 mm. It is a sense line into the
  regulator's ~1 MΩ internal divider, so noise decides its route, not
  length. It now also runs beside C12 and the enable row, and neither of
  those switches.
- **REG_EN still has two vias.** Both are on the long leg, 5.65 mm or more
  from switching copper, where issue 5 had one under the package.
- **The R8 silkscreen label sits over the FB trace.** Vias and tracks are
  tented, and DRC's silkscreen checks pass.

## Files

| file | content |
|---|---|
| `measure.py` | the measurements above, before vs after |
| `measurements.json` | its output for the previous and current board |
| `clearances.json` | `clearmin.py` before and after |
| `drc.json` | final DRC with schematic parity |
| `aperture-audit.json` | `via_openings.py` on the final board |
| `negative-tests.json` | the new floor, fired on two broken boards |
| `reg-en.png` | top and bottom copper round U3, before and after |
| `planes.png` | In1 and In2 under the buck block, before and after |

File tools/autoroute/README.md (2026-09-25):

# autoroute — the grid router used to wire Pixy-M2 on 2026-09-21

Not a general tool. It was written for this board and hard-codes its net names,
widths and the In2.Cu VBAT island.

    python3 wire.py      # reads base.kicad_pcb, writes ../../Pixy-M2.kicad_pcb
    python3 rework.py    # reads base-routed.kicad_pcb, writes ../../Pixy-M2.kicad_pcb
    python3 check.py     # per-net length / width / via report on the routed board
    python3 loop.py -v   # motor output pair loop areas (add paths to compare boards)

A full `rework.py` run takes a few minutes: the via-out-of-pad pass recomputes a
per-net distance field for each via it moves. Run it in the background rather than
waiting on it, and **do not watch it with `pgrep -f "python3 rework.py"`** — the
pattern matches the watching shell's own command line, so the loop never exits.

## wire.py — the original routing pass

`wire.py` expects an *unrouted* copy of the board as `base.kicad_pcb` in its working
directory, and rewrites the project file from scratch every run — it never edits
existing tracks. Re-running it discards all hand edits made since, so copy the board
aside first.

How it works: pads and holes are rasterised onto a 0.05 mm grid; per net a Euclidean
distance transform gives the legal region for that net's width (0.26 mm clearance
target against a 0.2 mm rule); A* over F.Cu + B.Cu with a via cost routes each net,
growing a connected group at a time. Plane nets get one stitching via per SMD pad
instead of being routed. A final pass widens power tracks wherever clearance allows.

Two tracks in the committed board were hand-corrected afterwards and are not
reproduced by a re-run: one ESP_3V3 segment at U4 narrowed 0.4 → 0.2 mm, and a short
segment added so MOT_B_2 lands on J9 pad 6's annulus rather than its rounded corner.

## rework.py — the motor-region second pass (review issues 1–3)

`rework.py` reads **`base-routed.kicad_pcb`**, a snapshot of `wire.py`'s output, and
writes the reworked board. Like `wire.py` it never edits the file it reads, so it is
re-runnable — but it also discards any hand edits made to `Pixy-M2.kicad_pcb` since,
and it emits the board with *unfilled* zones. Always follow it with:

    kicad-cli pcb drc --schematic-parity --refill-zones --save-board \
        --format json -o /tmp/drc.json ../../Pixy-M2.kicad_pcb

What it does, in order — the order matters:

1. moves C18, C20, C21 and four silkscreen reference fields (footprint moves must
   come before any track edit: they re-split the file and drop pending block edits);
2. rips the four motor nets, `/GPIO6`, and the VBAT/GND stubs in five boxes around
   the old capacitor and driver positions;
3. lays the hand-computed copper — driver pin escapes, the VM/GND runs across to each
   bypass cap, and the in-pad thermal vias — all of it clearance-checked by hand
   against the 0.5 mm pin pitch rather than searched;
4. routes the four motor trunks at 0.8 mm with A*.  `MOT_B_1` goes first; its
   finished polyline is then sampled, each sample offset 1.15 mm toward the side
   `MOT_B_2` has to end up on, and `MOT_B_2` is routed through those points so the
   two run as a pair (review issue 4).  An unreachable waypoint is skipped, not
   fatal.  `U4` is not paired — measured, no gain, see CLAUDE.md;
5. *then* searches for the plane stitching vias, so they cannot land on a trunk;
6. lays the buck block (`buck_block`, review issue 5) — same discipline: every
   track first, every via afterwards.  The first attempt did it the other way and
   dropped a ground stitching via straight into the corridor the switch node
   needed, shorting SW to GND under the package;
7. re-routes `/VSYS` (through a waypoint north of the buck, or A* threads the
   8.4 V input rail between L1 and the output capacitors), `/REG_EN` and
   `/GPIO6`, all of which were ripped to free space;
8. runs the historical centre-based relocation (`unstick_vias`) and its whole-net
   fallback. This stage alone misses drill-edge overlaps and paste-only pads;
   it is retained to reproduce the original routing, then corrected in step 10;
9. restores the verified local GPIO48 route with `encoder48_cleanup` (2026-09-22
   audit P3). The generic via relocation had stretched this encoder net to
   72.36 mm around TP5 and J11; the replacement is 26.03 mm, keeps the J8/R20/U1
   connections, and puts all four via holes at least 0.45 mm clear of SMD mask
   openings. This runs after the generic reroute so regeneration preserves it;
10. applies `finish_issue6.py`: 35 local via moves and their layer connections,
    with per-via fill/cap on the four intentional driver thermal vias;
11. lays the USB pair (`usb_pair.py`, review issue 7).  It rips the four USB
    nets and CC1/CC2, turns U2 to rot 90 so its flow-through pins face J1 and
    U1, hand-places the 0.25 / 0.15 mm pair J1 → U2 → U1 on F.Cu with no vias,
    takes U2's GND and VBUS out under the body, then A*-routes CC1/CC2 with the
    pair inflated 0.15 mm so they cross it on B.Cu and keep their vias clear.
    It runs last so that every stage before it replays unchanged; the U2 move
    therefore goes through `Pcb.sync()` (below) rather than the up-front MOVES;
12. lays the copper the issue-8 rule set requires (`issue8.py`): widens the five
    nets the router left at 0.15 mm to 0.2 mm outside the DRV8231A pin fields,
    re-routes the USB supply (`Net-(F2-Pad1)`, `/VBUS`) at 0.6 mm with the D3 tap
    pinned to its old corridor, and the R14 tap on `/VBAT_FUSED` at 0.8 mm;
13. moves J8/J9 to JST SH in the Pololu encoder pin order (`pololu_conn.py`,
    2026-09-23).  It swaps the two PH footprints for SH clones of J4, rips the
    motor trunks back to the driver escapes, drops other-net copper under the
    new pad rows, prunes what that leaves dangling *within 2 mm of the new
    pads only*, then re-routes: 0.6 mm fan-in stubs and paired 0.8 mm trunks on
    M1/M2, 0.2 mm reconnections for the cut signals, plane stitches for GND,
    VCC and the MP pads, and U4's VREF feed (its B.Cu run to the old
    through-hole J8 pin was the only 3V3 path under the In2 VBAT island).
    It also sets R17/R18 to 2.2 kΩ.  `! no stitch via for GND near …` for
    J8.1, J8's west MP and J9.1 is **expected**: those pads are then tied to
    the nearest stitched pad or GND via;
14. replaces F1 with a Littelfuse 885 fuse (`f1_fuse.py`, 2026-09-23): builds
    the footprint from the stock library file, moves BT1 0.4 mm north so its
    courtyard fits, drops the stubs left on the old 2920 pads, and re-routes
    `/VBAT_RAW` and `/VBAT_FUSED` at 1.0 mm;
15. points U1 at the project footprint `Pixy-M2:ESP32-S3-WROOM-1_AntennaOverhang`
    (`Pcb.set_fpid`), matching the schematic, so the placed copy matches its
    library (see `layout/drc-clean/`);
16. prints the assembly marks on the silkscreen (`assembly_marks.py`,
    2026-09-23): the four ToF mount outlines with aim arrows and connector
    names, the Adafruit BNO085 outline with its holes, chip centre and X/Y
    axes on F.SilkS, and both Pololu N20 bodies on their wheel axles on
    B.SilkS.  It nudges the C20 and R15 reference fields clear of the IMU
    outline.  Standalone, it adds the marks to an existing board once;
17. moves the battery bay between the axles (`battery_bay.py`, 2026-09-24):
    the underside battery rule area goes to board x 0.5-66, y 57.5-74.5 (the
    62 x 17 mm pack plus its lead exit), both motor reservations turn their
    4 mm encoder allowance outboard, and User.1 / User.2 are redrawn to match,
    with the pack's lead route to BT1.  On B.SilkS it prints the pack
    outline, its lead arrow and the route as a dashed line (the motor names
    and `ENC CONN SIDE` come from `assembly_marks.py`).  Every edit asserts
    the placement-era geometry it replaces.  Standalone, it converts an
    existing board once, moving the motor names on a board marked before
    2026-09-24, and checks every drilled pad against the new envelopes and
    bands;
18. moves the UVLO enable network beside U3.2 (`reg_en.py`, 2026-09-24).
    C13 and R8 stand vertical in a row just west of U3, so EN -> C13.1 ->
    R8.1 is one straight top-layer run.  The FB sense trace keeps its
    via-free top-layer route to C11.1, but it now turns south round the
    outside of the new parts.  REG_EN's long leg to R7/R9 crosses under it on
    B.Cu.  The VSYS hop from C12 to C17 moves its upper via north of FB.
    Everything is hand-placed, and every old item is asserted before it is
    replaced.  Standalone, it converts an existing board once;
19. adds the F.Cu `GND pour motor region` zone, the two `Motor pin escape` rule
   areas and the `Power pin escape` rule area that `Pixy-M2.kicad_dru` conditions
   on, and the `Dwgs.User` fab note;
20. serializes a temporary candidate and runs `via_openings.py` before replacing
    the output PCB. Any missing expected via or aperture violation stops the run.

The final aperture check measures drill edges against mask and paste, including
independent paste-only pads, rotated pads and rounded corners. It requires
0.10 mm clearance except for the four explicitly filled/capped driver thermal
vias. To check an edited board without regenerating routing, run from repo root:

    /usr/bin/python3 tools/autoroute/via_openings.py Pixy-M2.kicad_pcb --output /tmp/apertures.json
    /usr/bin/python3 tools/autoroute/test_via_openings.py

The first command exits nonzero on a violation; it complements, not replaces,
KiCad DRC and schematic parity. See `layout/issue6-complete/README.md`.

`! no neck+via for GND from (109.0,114.8)` and the same for `(117.0,114.8)` are
**expected output**, not failures: the ESP_3V3 VREF feed blocks a wide neck out of the
lower end of each exposed pad. Nothing is emitted when that search fails.

## supporting modules

| file | role |
|---|---|
| `sexp.py` | minimal s-expression reader |
| `load.py` | footprint / pad extraction with rotation applied |
| `board.py` | 0.05 mm raster helpers, board outline fill, keepout zones |
| `grid.py` | obstacle raster of the **current** board — pads *and* existing tracks, vias and holes — with per-net distance fields. This is what lets `rework.py` route against a board that is already wired, which `wire.py` could not do |
| `pcbedit.py` | text-level surgery on the `.kicad_pcb`: add/drop segments and vias, move footprints, their pads' and texts' angles and board-level labels, append zones. **A footprint or text edit re-splits the file from `self.text` and drops any track/via edit not yet in it** — which is why `rework.py` does its moves first; a late move must call `sync()` first to fold pending block edits back in. **Rotating a footprint must rotate every `(at …)` inside it** — pads included, since each stores its angle in the board frame. Miss them and DRC reports `lib_footprint_mismatch`, which reads like a library problem rather than a bad edit |
| `issue8.py` | review issue 8: the copper the Power/Battery/signal-width rules require. Two router caveats live here: `Router.route_waypoints` offers each waypoint on both layers, so consecutive legs can meet on different layers with no via between them (pin waypoints to one layer); and `G.smd_block` keeps via *centres* only 0.15 mm off SMD pads, which lets a drill touch the mask opening — `issue8.py` rebuilds it at drill radius + 0.10 mm for its own stage |
| `usb_pair.py` | review issue 7: U2 rotation, the hand-placed USB pair, and the CC1/CC2 reroute around it. Geometry constants (`WIDTH`, `GAP`, `U2_AT`, `GND_VIA`) are at the top; the impedance behind them is `../impedance/zdiff.py` |
| `pololu_conn.py` | the J8/J9 connector swap (step 13).  Its `prune()` subtracts a baseline taken before the swap, because on plane nets every bare stitching via looks dangling, and it only trims near the new pads: pruning a cut GPIO40 all the way back ate the 0.15 mm DRV8231A pin escape, which the router cannot re-create.  Its dangling test counts a T onto a segment only if that segment does not share an end with the one tested, because the router's 0.05 mm staircase steps each lie within half a width of the next |
| `f1_fuse.py` | the F1 swap (step 14).  Reuses `pololu_conn.py`'s rip / prune / reconnect helpers; its pruning zone is the pads' *extent* plus 2 mm, since F1's pads are 7.3 mm tall and a zone built from pad centres missed a track under the pad's own edge |
| `assembly_marks.py` | silkscreen marks for the off-board parts (step 16). Every dimension is a constant at the top: the ToF reservations, Adafruit's BNO085 board geometry (from `Adafruit_BNO08x.brd`) and Pololu's gearbox / motor / encoder lengths (drawing 0J949). Each part's marks are one KiCad group, so they move together in the GUI |
| `battery_bay.py` | the battery bay (step 17). Its constants are KiCad coordinates, old and new side by side, so a changed board fails an assertion instead of being half-edited. `check()` repeats `layout/verify_placement.py`'s drilled-pad test against the new envelopes on a routed board, which that script cannot load |
| `reg_en.py` | the enable network beside U3.2 (step 18). FB could not drop to B.Cu to make room: a via on it bonds to the In2 3V3 pour beside U3, which is the plane pickup review finding 5 removed. So FB stays on top and REG_EN's long leg, a signal-only net, takes the two vias. The new vias sit at least 1.35 mm from any other non-plane via, so their antipads never merge into one void in In1 or In2 |
| `loop.py` | enclosed loop area of each motor output pair, the metric review issue 4 turns on. Run it on two boards to compare. The connector end of each pair is looked up by net, so it measures boards from before and after the J8/J9 re-pin alike. Chains track endpoints by BFS over a node graph — a greedy nearest-endpoint walk takes shortcuts through via branches and silently reports the straight-line quadrilateral between the four pads no matter how the board is routed, which is a convincing-looking wrong answer |

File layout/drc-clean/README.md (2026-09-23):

# DRC clean: J1 hole clearance and the U1 footprint warning (2026-09-23)

Five DRC items had been carried since placement (`layout/README.md`, "Five
retained DRC findings"): four J1 `hole_clearance` errors and one U1
`lib_footprint_mismatch` warning. Neither was a routing fault. Both are now
resolved without changing any copper. KiCad reports **0 violations, 0
unconnected items, and 0 schematic-parity issues** (`drc.json`), and ERC still
reports 0 (`erc.json`).

## J1: four hole-clearance errors

J1 uses the stock KiCad footprint `Connector_USB:USB_C_Receptacle_Amphenol_12401948E412A`.
The earlier CLAUDE.md note named `USB_C_Receptacle_Amazon`. That was wrong: the
`.kicad_mod` of that name in the repository root is unused.

The footprint's four GND pads (A1/B12 and A12/B1, 0.8 × 1.4 mm) end at
y = −4.40 mm. Its 0.6 mm locating holes start at y = −4.15 mm. That leaves
**0.25 mm**, against the project's 0.30 mm hole-clearance rule. The four reports
are duplicate pad numbers over two physical gaps.

**This is the manufacturer's land pattern, so the land pattern stays.** The
footprint cites Amphenol drawing c12401948. KiCad's librarians merged it against
that drawing in kicad-footprints MR !3540. Amphenol's own site blocks automated
download, so I could not re-measure the drawing myself. Shortening the GND
pads would move the part off its recommended layout to satisfy a rule the
fabricator doesn't need. JLCPCB's capabilities page gives **0.20 mm**
NPTH-to-track.

**How the rule changed.** KiCad's board-setup hole clearance is absolute: a
custom rule cannot relax it, the same as the minimum track width (issue 8). So:

- the board setup `min_hole_clearance` is **0.30 → 0.20 mm**, the fab floor;
- a new custom rule, **"Hole clearance"**, restores **0.30 mm for every pair
  except J1's own pads against J1's own holes**.

Everything else on the board is held to exactly what it was before.

**Negative tests** (`negative-tests.json`):

| edit | fires |
|---|---|
| a track 0.25 mm from an SW3 locating hole (not J1) | "Hole clearance", 0.30 mm |
| J1's hole moved to 0.15 mm from its own GND pads | the 0.20 mm board-setup floor |

## U1: library-footprint mismatch warning

U1's board copy differed from `PCM_Espressif:ESP32-S3-WROOM-1` in exactly five
items: the four antenna-area outline lines and the "Antenna Area" label, moved
from F.SilkS to F.Fab. The module's antenna deliberately overhangs the board
edge, so the silkscreen would print off the board. The change was intentional
and recorded in `layout/README.md`. Pads, courtyard, antenna keepout and 3D
model are identical to Espressif's.

"Update footprint from library" would have undone the change, so that was not
the fix. Instead the variant is now a real library footprint:

- `Pixy-M2.pretty/ESP32-S3-WROOM-1_AntennaOverhang.kicad_mod` is Espressif's
  file with those five layer changes, a new name, and a description saying why.
  `diff` against the Espressif original shows nothing else.
- `fp-lib-table` (project) adds library `Pixy-M2` at `${KIPRJMOD}/Pixy-M2.pretty`.
- U1 points at `Pixy-M2:ESP32-S3-WROOM-1_AntennaOverhang` in both files:
  - the board, as a one-line change;
  - the schematic's **placed U1 instance only**. Changing the cached library
    symbol as well produced an ERC `lib_symbol_mismatch`, so it was left as
    Espressif's.
- `rework.py` sets the same footprint id when it regenerates the board
  (`Pcb.set_fpid`). A full replay reproduces HEAD's tracks and vias exactly.
  The board file itself was edited in one line rather than regenerated, to
  keep the diff free of UUID churn.

## Not changed

No copper, footprint geometry or placement changed. The committed board differs
from the previous commit only in U1's footprint id.

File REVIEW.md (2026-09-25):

# Pixy-M2 layout review — 2026-09-21

> **Status, 2026-09-22: findings 1–8 are fixed on the board.** Finding 7: U2
> turned 90° so its flow-through pins face J1 and U1, and D+/D− run as one
> 0.25 / 0.15 mm pair (field-solved ≈ 88–94 Ω; confirm with the fab) from J1 to
> U1 on F.Cu over the In1 plane with **no vias** — the connector-side D− had 4
> and 8 mm of B.Cu. End-to-end skew 8.08 → 1.04 mm. A `USB` netclass and three
> DRC rules enforce it; see `layout/issue7-usb/README.md`. Finding 8: `Battery`
> and `Power` netclasses; DRC floors for every signal (0.2 mm, pin fields
> excepted), the USB and battery supply paths (0.5 / 0.8 mm), and clearance
> guards on `REG_EN`, `VBAT_SENSE` and the IPROPI lines. The rules caught real
> copper, now fixed: 219 mm of 0.15 mm signal track (8.7 mm left, all in the
> driver pin fields), and a USB supply that was 0.24 mm end to end (VBUS
> 105 → 44 mΩ). Every rule was shown to fire on a deliberately broken copy. Two
> clearance floors are recorded below the CLAUDE.md intent rather than met:
> `REG_EN` 0.40 mm from the SW pin, IPROPI 0.29 mm from motor copper; see
> `layout/issue8-rules/README.md`. The shield-return and D6 side observations
> are untouched. DRC verdict unchanged throughout.
> **2026-09-23: DRC is clean** — 0 violations, 0 unconnected, 0 parity issues. The
> J1 pad-to-hole gaps are the Amphenol land pattern, now allowed at JLCPCB's
> 0.20 mm by a rule scoped to J1's own pads and holes (0.30 mm everywhere else);
> U1's antenna-silkscreen customization moved into a project library footprint.
> See `layout/drc-clean/README.md`.
> **2026-09-24: the REG_EN floor recorded under finding 8 is fixed.** R8 and C13
> now sit beside U3.2, and the EN via under the package is gone. REG_EN's closest
> approach to the switch node is U3's own EN-to-SW pin gap, 0.95 mm; it was
> 0.40 mm. The DRC floor is now 0.9 mm. FB keeps its via-free top-layer sense to
> C11. That run passes TP4 at 1.35 mm, not the 2.1 mm stated for finding 5 below.
> See `layout/reg-en/README.md`.
> The fix is a single reproducible pass, `tools/autoroute/rework.py`, run against a
> snapshot of the routed board; DRC after it is byte-for-byte the same verdict as
> before (0 unconnected, 0 schematic-parity issues, only the four pre-existing J1
> `hole_clearance` errors and the U1 `lib_footprint_mismatch` warning). What changed,
> with measurements, is written up under "Motor-region rework" in `CLAUDE.md` /
> `AGENTS.md`. Headline numbers: the motor-B pair goes from 0.267 Ω to 0.066 Ω
> (0.393 V / 0.578 W → 0.096 V / 0.141 W at 1.47 A), each driver's exposed pad gains
> two in-pad thermal vias plus 165 mm² of F.Cu ground pour, and C18/C20 move from
> 4.95 mm / 3.61 mm to 1.33 mm from their VM pin with the loop closed in top copper.
> Finding 4 was then fixed by pairing the motor-B outputs rather than by moving U5:
> the enclosed loop goes 423.6 → 111.5 mm², mean separation 7.17 → 1.39 mm, and motor
> copper to `REG_EN` 0.27 → 8.51 mm, to the SW node 0.28 → 6.62 mm. U5 stayed put
> because J9 sits off the In2 VBAT island and next to the buck output — see
> "Issue 4" in `CLAUDE.md` for the full argument and the two costs it carries.
> Finding 5 followed on 2026-09-22: six parts moved and the regulator block hand
> routed. TP4's two vias and 2.55 mm of back-layer switch-node copper are gone (the
> node is now 3.57 mm² on one layer with no vias), C17 straddles U3's IN and GND pins
> so the two return vias are 0.95 mm apart instead of 5.88 mm, L1 → C7 → C11 is a
> single top-layer run where no copper joined them at all before, and FB has its own
> sense trace to C11 that stays 2.1 mm clear of the switch node. One regression is
> recorded there too: REG_EN now passes 0.99 mm from switching copper, having moved
> out of a via-in-pad.
> Finding 6 was completed in a follow-up: the earlier centre-only check missed
> 12 drill overlaps and 23 additional vias below 0.10 mm edge clearance. Those
> 35 vias now clear all pad mask/paste openings by at least 0.10 mm. The four
> intentional U4/U5 thermal vias remain under independent paste apertures and now
> explicitly specify filling and capping per via, which KiCad 10 supports. The
> fabrication note requires resin fill and copper cap (IPC-4761 type VII); the
> order must include that process. A persistent DRC rule and an aperture audit
> protect this correction. See `layout/issue6-complete/README.md` for validation.

The saved layout needs another routing pass before fabrication. The most consequential findings are undersized motor-output copper and inadequate thermal copper around the motor drivers. The segmented bends themselves are not a manufacturing defect.

Reviewed the current, uncommitted PCB on disk using KiCad 10.0.5. Refilled zones and ran DRC plus schematic parity on a temporary copy; exported a fresh schematic netlist; extracted pad, track and via geometry; inspected all four copper layers. No electrical or mechanical design files were changed. Source SHA-256: `7c847069c641a7e9ac56d550b5bf75c23de3d4db644b60ffecd3322e98b71fdd`.

Coordinates below are absolute KiCad millimetres. Board front-left is (100, 60). Measurements describe geometry; noise and temperature consequences are engineering assessments, not simulation or hardware test results. The figures highlight track centerlines and pad envelopes; copper planes are omitted in these illustrations.

1. **High priority: motor outputs have long 0.15 mm sections.**

   | Net | Total track length | Length at 0.15 mm |
   |---|---:|---:|
   | MOT_A_1 | 15.02 mm | 10.99 mm |
   | MOT_A_2 | 16.24 mm | 6.35 mm |
   | MOT_B_1 | 41.95 mm | 38.80 mm |
   | MOT_B_2 | 48.06 mm | 40.73 mm |

   These are extended narrow runs, not merely short escapes from WSON pads. For example, MOT_B_1 is 0.15 mm wide for the entire 19.5 mm segment from (119.55, 113.10) to (139.05, 113.10). MOT_B_2 has another 15.65 mm straight segment of the same width near y=97.50.

   Using the board's specified 35 µm outer copper and copper resistivity at 20°C, the two motor-B traces together have approximately **0.268 Ω** resistance. At a sustained 1.47 A, that is approximately **0.394 V drop and 0.579 W copper loss**. This excludes connectors, vias and rising copper resistance with temperature. PWM operation changes average heating according to RMS current; this calculation does not establish an actual trace temperature.

   Reroute motor trunks with broad copper throughout, retaining fine necks only where necessary immediately at pads. The intended 0.8 mm trunk width is a useful starting point, with final sizing against current, copper and allowed temperature rise. Define a motor-specific minimum-width rule so DRC catches extended necks.

   [Motor routing illustration](/home/galm/Workspace/KiCad/Pixy-M2/Pixy-M2/layout/review-2026-09-21/motors.png)

2. **High priority: U4's exposed pad has a poor heat path; U5 also needs better heat spreading.**

   U4 pin 9 is at (109, 114), with a 0.9 × 1.6 mm copper pad. There is **no via inside it**. Its external copper connection is a 0.4 mm trace to a single ground via at (109, 112.75). U4's pin-7 ground via is separate; it is not a via underneath the exposed pad. U5 has one via inside its exposed pad at (117.20, 113.75), plus the offset connection above the package. There is no top ground pour around either driver.

   This is materially different from the routing note claiming two vias per exposed pad. Ground connectivity is correct; the concern is heat flow. At high motor current, relying on a small pad and narrow neck creates avoidable thermal-shutdown risk. Add broad exposed-pad ground copper and appropriate thermal vias to the ground plane, coordinating via treatment with assembly. TI recommends maximizing thermal copper and connecting the exposed pad to top/internal ground through vias. [DRV8231A datasheet, layout section](https://www.ti.com/lit/ds/symlink/drv8231a.pdf)

   [Driver copper illustration](/home/galm/Workspace/KiCad/Pixy-M2/Pixy-M2/layout/review-2026-09-21/driver.png)

3. **High priority: motor bypass capacitors do not form compact local supply loops.**

   C18's VBAT pad is 4.95 mm from U4 VM; C20's is 3.61 mm from U5 VM, measured pad-center to pad-center. More significantly, each capacitor connects to its own plane vias, while each VM pin reaches the VBAT plane through a 0.15 mm × 0.762 mm track and one via. There is no direct top-layer capacitor-to-VM connection. Their grounds also return independently through the plane.

   The stackup separates the L2 ground and L3 power planes by a 1.065 mm core. Those plane connections therefore do not substitute for a tight local bypass loop. Move/orient C18 and C20 beside the VM/GND side of each driver and close the switching-current loop locally with short, broad copper. Keep C19/C21 nearby. This reduces supply ringing and noise injected into the shared rails. TI's layout guidance calls for close VM capacitors and thick high-current connections. [DRV8231A datasheet](https://www.ti.com/lit/ds/symlink/drv8231a.pdf)

4. **Medium priority: motor B takes two widely separated routes, including through the buck area.**

   U5 is at (117, 114), while J9 is at (158, 107). MOT_B_1 traverses approximately y=113.1, whereas MOT_B_2 detours through approximately y=97.5–97.6, immediately below U3's VIN/GND pads and beside its enable network. The two outputs are about 15 mm apart across part of the board.

   This spreads switching current across the regulator region and increases motor-loop area. Widening the same route alone will not fix its placement. Move U5 and its supporting parts toward J9, or find a paired route through the motor region away from the buck. Preserve the accepted connector pinout; the avoidable separation is on the PCB.

   [Buck-area illustration](/home/galm/Workspace/KiCad/Pixy-M2/Pixy-M2/layout/review-2026-09-21/buck.png)

5. **Medium priority: the buck power stage needs more deliberate local routing.**

   TP4 extends the SW node onto B.Cu through two vias at (142.85, 96.85) and (142.85, 99.40), joined by a 2.55 mm bottom trace. This is a test-point branch, not the main U3-to-L1 path; nonetheless, it unnecessarily spreads switching copper across both faces.

   C6 is about 5 mm above U3, creating extended bootstrap connections. C17 is reasonably close to VIN (1.87 mm pad-center distance), but its ground via and U3's ground via are approximately 5.88 mm apart. L1 output, C7/C11 and FB each independently connect to the 3V3 plane; there is no compact top output-filter connection or dedicated feedback pickup at the output capacitor.

   Rework this as a compact regulator block: place C6 beside BST/SW, close the input/output loops locally, take a quiet feedback sense from the output-capacitor node, and shorten or remove TP4's branch. There is no claim that the fixed-voltage regulator needs a feedback divider. The component manufacturer's reference layout is the appropriate starting point. [AP63203 datasheet, page 15](https://www.diodes.com/assets/Datasheets/AP63200-AP63201-AP63203-AP63205.pdf)

6. **Medium priority: several unfilled vias lie inside solder pads.**

   Examples include U2 pin 1 at (152.40, 147.15), U3 EN at (137.60, 96.05), U5's exposed pad, several U1 pads and L1's output pad. These are 0.3 mm drills. The board specifies front/back tenting but no filling or capping. Where a via lies inside a pad's mask opening, the pad opening exposes the hole despite the general tenting setting.

   Solder can wick into these holes, especially troublesome for small IC pads. Move ordinary signal vias outside solderable pad areas. For intentional thermal via-in-pad, specify an assembly-compatible hole, stencil and filling/capping process. Confirm the actual order option; tenting and filled/capped via-in-pad are different processes. [JLCPCB via covering guidance](https://jlcpcb.com/help/article/pcb-via-covering)

7. **Medium priority: USB is not routed as a controlled differential pair.**

   U2-to-U1 D+ and D− are 18.43 and 13.74 mm of 0.2 mm copper with varying separation and a pronounced D+ detour around U2. Before U2, D− changes to B.Cu and back through two vias while D+ remains on F.Cu. These asymmetric layer transitions matter more than the visual bend style.

   The two connector-side net lengths are 5.52 mm and 9.83 mm. Do not interpret the 4.69 mm difference after U2 as the entire end-to-end skew: the difference before U2 partially offsets it, and the connector nets contain branches.

   Reorient U2 if useful and route both sides as a consistent pair against the chosen JLCPCB stackup. Espressif specifies parallel, matched routing at 90 Ω ±10%, a continuous reference, and minimized transitions. This is a robustness/compliance concern; these short Full Speed routes are not proof that USB will fail. [Espressif USB layout guidance](https://docs.espressif.com/projects/esp-hardware-design-guidelines/en/latest/esp32s3/pcb-layout-design.html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)

   [USB routing illustration](/home/galm/Workspace/KiCad/Pixy-M2/Pixy-M2/layout/review-2026-09-21/usb.png)

8. **Medium priority: project rules do not encode the electrical routing requirements.**

   The project has only the Default netclass, no netclass assignments and a global 0.15 mm minimum track width. It has no motor-specific width constraint and no enforceable USB pairing/impedance geometry. This explains why the narrow motor traces pass DRC. Configure those requirements before rerouting, with narrowly scoped pad-escape exceptions where needed.

Additional review observations:

- GPIO2 and GPIO10 current-sense nets have 52.02 and 40.67 mm of track. Some sections run alongside drive-control signals. Improve isolation where convenient during motor rerouting; validate current readings during switching on hardware. Their 1.5 kΩ conversion resistors mean these are not the same 150 kΩ source impedance as VBAT_SENSE. Length alone is insufficient evidence of a fault. [Current-sense routing illustration](/home/galm/Workspace/KiCad/Pixy-M2/Pixy-M2/layout/review-2026-09-21/sense.png)
- The shield net has 32.26 mm total branch copper and a bottom-layer detour behind U2. Shorten the shell-to-C8 return during USB rework; the long narrow path adds inductance to the intended ESD return. This does not challenge the existing shield RC topology.
- Mechanical attachment is still provisional. There are reservation drawings but no dedicated chassis mounting holes. Confirm the actual clamp/bracket/adhesive scheme and motor, battery, cable and antenna clearances before ordering; holes are not mandatory if the chosen attachment method does not need them.
- D6 has two VBAT vias but one ground via. A broader local return and more ground stitching are useful while rebuilding the motor power region. Its actual surge performance requires measurement.

Checks that did not reveal a new flaw:

- **Zero unconnected items and zero schematic-parity issues.** No track short, copper-clearance or courtyard error was reported by the fresh check.
- L2 is a continuous ground plane with no signal routing. The antenna overhang has all-layer copper exclusions; no copper violation was reported there. This does not validate RF clearance to external mechanics.
- The remaining DRC errors are four duplicate-pad reports of two physical 0.25 mm pad-to-NPTH gaps inside J1, against the project's 0.30 mm rule. JLCPCB lists 0.20 mm NPTH-to-track clearance, so these are not automatically a fabrication rejection. Reconcile the connector land pattern and applicable fabricator clearance before changing or excluding the rule. [JLCPCB capabilities](https://jlcpcb.com/capabilities/pcb-capabilities)
- The single U1 library-footprint mismatch warning corresponds to a previously documented footprint customization; it is not evidence of a net or pin-map error.

Evidence: [fresh DRC report](/home/galm/Workspace/KiCad/Pixy-M2/Pixy-M2/layout/review-2026-09-21/drc.json) and [per-net measurements](/home/galm/Workspace/KiCad/Pixy-M2/Pixy-M2/layout/review-2026-09-21/measurements.json). Total extracted routing is 1694 track segments, 242 vias and 2241.44 mm of copper centerline. No thermal, signal-integrity or EMC simulation was performed, and this was not a complete component-rating or BOM audit.

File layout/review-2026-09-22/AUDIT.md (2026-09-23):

**Audit of Claude's fixes — 2026-09-22**

Follow-up: **P3's encoder detour has been resolved**, reducing GPIO48 to 26.03 mm.
See the [fix and validation](/home/galm/Workspace/KiCad/Pixy-M2/Pixy-M2/layout/encoder-p3-fix/README.md).
The findings and measurements below describe the audited `86f2628` snapshot.

Issues 1–5 are substantively addressed in the copper. Issue 6 is **not fully fixed**: 12 unintended via holes still overlap solder-pad openings, in addition to the four intentional driver thermal vias. The issue-6 reroute also worsened USB D−, and introduced a large, unnecessary encoder detour. I would not accept the blanket “findings 1–6 are fixed” statement in `REVIEW.md`.

Reviewed HEAD `86f2628` against routed baseline `3a8bd96`, with `e802e25` used to isolate the final via-relocation pass. PCB SHA-256: `dff608a097b87df66954081140b5fe07cb19f2f9c4d8a6019298e1b60e6f39a9`. KiCad 10.0.5. The board, schematic, project settings, and original review were left unchanged; only this audit and its evidence were added. Coordinates are absolute KiCad millimetres.

**Verification of the six fixes**

| Original issue | Verdict | Evidence and qualification |
|---|---|---|
| 1. Undersized motor outputs | Fixed in the layout | All four trunks are 0.8 mm. Widths below 0.5 mm are restricted to the driver escapes: 2.50 mm on each OUT1, 0.995 mm on each OUT2. The new minimum-width rule actually works: deliberately narrowing one trunk on each net, on a disposable copy, produced four corresponding violations. |
| 2. Driver thermal paths | Copper fix verified; assembly process remains a dependency | Each exposed pad has two 0.45/0.25 mm vias, a broad connection northward, and six GND vias total within 3 mm of its centre. The filled top ground pour is present and connects to the thermal copper. The four in-pad holes still require the specified fill-and-cap process. This is not a thermal qualification at sustained stall current. |
| 3. Motor bypass loops | Fixed | C18/C20 now sit 1.329 mm pad-centre to VM-pad-centre away. Each has direct top-layer VM and GND connections to its driver. The high-frequency bypass loop no longer depends on separate power-plane taps. Local bulk capacitance is retained. |
| 4. Motor-B routing through the buck | Substantively fixed | The outputs now share the corridor below the buck instead of taking widely separated routes through it. U5 did not have to move to solve the original placement problem. MOT_B_2 uses seven vias, so the result is not a uniformly paired, single-layer route; nevertheless, the original excursion through the regulator is gone. |
| 5. Buck placement/routing | Substantively fixed, with compromises | SW has no vias or bottom copper; C6 is closer; C17 directly spans the IN/GND sides; the two nearby return vias are 0.951 mm apart; L1/C7/C11 have a direct top output connection; FB has a separate sense trace to C11. C6 placement and the long FB trace are compromises, not newly demonstrated faults. C12 remains the bulk input capacitor; C17 is the local 100 nF bypass. |
| 6. Vias in solder pads | **Incomplete** | The via-centre test misses holes that overlap a pad edge. Independent geometry and a temporary physical-hole DRC rule both expose the remaining problem. Details below. |

Motor trace resistance, calculated from actual segment widths and lengths using 35 µm copper and resistivity at 20°C:

| Net | Track length | Track resistance |
|---|---:|---:|
| MOT_A_1 | 16.65 mm | 14.38 mΩ |
| MOT_A_2 | 18.96 mm | 12.49 mΩ |
| MOT_B_1 | 43.51 mm | 30.91 mΩ |
| MOT_B_2 | 59.41 mm | 37.40 mΩ |

Motor B's combined track resistance is approximately 68.3 mΩ, versus 268 mΩ originally: approximately 0.100 V drop and 0.148 W at 1.47 A. These estimates exclude via barrels, connectors, pad spreading resistance and temperature rise. The improvement is real; neither those numbers nor a trace-current calculator establish the assembled board's temperature.

The thermal and bypass changes follow the intent of [TI's DRV8231A layout guidance](https://www.ti.com/lit/ds/symlink/drv8231a.pdf), and the buck changes address the original concerns against the [AP63203 reference layout](https://www.diodes.com/assets/Datasheets/AP63200-AP63201-AP63203-AP63205.pdf).

[Actual filled motor-region top copper](/home/galm/Workspace/KiCad/Pixy-M2/Pixy-M2/layout/review-2026-09-22/motor-top.png) · [Buck routing](/home/galm/Workspace/KiCad/Pixy-M2/Pixy-M2/layout/review-2026-09-22/buck.png)

**P2 — Issue 6 still leaves unintended holes exposed to solder**

The remaining unintended overlaps are:

| Part/pad | Unique holes | Example via centre | Hole penetration into nominal pad opening |
|---|---:|---|---:|
| U1, ground pad 41 | 7 | (133.60, 149.15) | Six holes overlap by 0.100 mm; the seventh by 0.010 mm |
| Q1, drain pads 6/7/8 | 3 | (126.50, 95.35) | 0.059–0.074 mm, accounting for rounded pad corners |
| U5, IPROPI pad 1 | 1 | (115.80, 113.05) | 0.074 mm |
| R22, pad 2 | 1 | (157.40, 111.70) | 0.046 mm |

For example, U1's 0.9 mm square pad at (133.10, 149.14) ends at x=133.55. The neighbouring 0.3 mm drill centred at x=133.60 begins at x=133.45. Its centre is outside the pad, but its hole overlaps the opening by 0.10 mm. The board has zero nominal mask expansion here, so this is already an overlap in the requested artwork, before fabrication tolerances.

`stuck_vias()` in `tools/autoroute/rework.py` tests whether a via **centre** is inside the pad rectangle. It does not test the whole drill against the opening. Consequently these holes escape the final “no via left in a solder pad” check. There are also zero-margin tangencies, including vias beside C7 and C11; these are not included in the 12 positive overlaps.

The four intentional thermal vias sit directly under the separate paste apertures in the U4/U5 footprints. Counting only whether the electrical pad itself has `F.Paste` misses those apertures. The documentation's “0 under solder paste” total is therefore also wrong: the physical aperture audit finds 16 overlapping holes, including the four intentional thermal ones.

Repair the check to compare the complete drill circle with every relevant mask opening, including corner geometry and a positive manufacturing margin. Move the unintended holes or explicitly include them in an approved filled/capped process. Recheck paste-only apertures separately. Update the fabrication note, which currently claims only four holes lie in pad openings. [JLCPCB distinguishes ordinary tenting from the filled/capped process used for via-in-pad assembly](https://jlcpcb.com/help/article/pcb-via-covering).

[U1 overlap illustration](/home/galm/Workspace/KiCad/Pixy-M2/Pixy-M2/layout/review-2026-09-22/u1via.png) · [All 16 overlapping holes, including the intentional four](/home/galm/Workspace/KiCad/Pixy-M2/Pixy-M2/layout/review-2026-09-22/overlapping-holes.csv)

**P2 — The final pass worsens the existing USB issue**

This is a regression of original issue 7, not an unrelated new defect. The via-relocation pass ripped and rerouted the connector-side D− net alone:

| Connector-to-U2 net | Before final pass | Current |
|---|---:|---:|
| D− total branch track length | 9.83 mm | 17.91 mm |
| D− vias | 2 | 4 |
| D+ total branch track length | 5.52 mm | 5.52 mm |
| D+ vias | 0 | 0 |

D− now detours around the R1/C1 area while D+ still goes directly to U2. The additional layer changes and greater separation worsen the pair geometry. These are total branched-net lengths, **not end-to-end differential skew**. They do not prove that a short Full Speed USB connection will fail.

Route both polarities together when fixing issue 7, including the connector branches and the ESD footprint. Avoid treating a differential signal as an arbitrary net during via repair. [Espressif calls for parallel, matched 90 Ω ±10% routing and minimized via transitions](https://docs.espressif.com/projects/esp-hardware-design-guidelines/en/latest/esp32s3/pcb-layout-design.html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).

[Current USB routing](/home/galm/Workspace/KiCad/Pixy-M2/Pixy-M2/layout/review-2026-09-22/usb.png)

**P3 — Newly introduced encoder detour, worth cleaning up**

GPIO48, the J8 encoder channel with R20's pull-up, grew from 21.61 to 72.36 mm of total copper in the final pass, and from three to four vias (the original baseline had two). It now travels west around TP5, down past J11, then east and back up to U1. GPIO47 remains about 21 mm. This detour adds avoidable trace capacitance and routed area to an external sensor input; with an open-collector encoder, added capacitance also loads the 10 kΩ pull-up.

This is a routing-quality regression, **not evidence of missed encoder counts**. Actual edge integrity depends on the selected encoder output, cable, edge rate and receiver configuration. Restore a short local route while keeping vias outside openings, and check the waveform during motor switching. No need to length-match the two quadrature channels merely because they differ in length.

[Encoder detour](/home/galm/Workspace/KiCad/Pixy-M2/Pixy-M2/layout/review-2026-09-22/encoder-full.png)

**Documentation corrections that should not be mistaken for additional PCB failures**

- The stated SW-node copper area of 3.57 mm² cannot describe the entire node: L1's SW pad alone is 3.60 mm². A polygon union including pads and tracks gives approximately 8.97 mm² on F.Cu now, versus 9.39 mm² on F.Cu plus 1.58 mm² on B.Cu originally. Eliminating the bottom branch is still an improvement; the published area metric overstates what was removed.
- The current refilled motor top zone measures approximately 205.94 mm² total, shared by the motor region. It is not 165 mm² separately available to each driver. Copper area alone is not a thermal model.
- The 0.45/0.25 mm thermal vias are not automatically a JLCPCB annular-ring violation. Their dimensions meet the separate published **via** diameter/hole guidance. Do not incorrectly apply JLCPCB's component-PTH annular-ring minimum to them. [JLCPCB capabilities](https://jlcpcb.com/capabilities/pcb-capabilities)

**Checks and limits**

Fresh zone refill and schematic-parity DRC on a temporary copy returned **0 unconnected items, 0 schematic-parity issues**, and exactly the existing four J1 hole-clearance reports plus the U1 library-footprint warning. The schematic has no diff from the baseline. L2 remains one continuous filled ground region. No new copper short, courtyard collision, outline violation or antenna-keepout violation was reported.

The ordinary DRC result does not cover same-net solder-wicking geometry. A separate temporary rule, `(constraint physical_hole_clearance (min 0.1mm))` for via/SMD-pad pairs, produced 44 additional diagnostic reports, including intentional thermal holes, duplicate pad reports and near misses. That 0.1 mm diagnostic threshold is an audit margin, not a claim that all 44 are distinct JLCPCB violations. The independent signed-distance calculation isolates the 12 unintended positive overlaps above.

Beyond those findings, I did not confirm another distinct new functional defect. Original open concerns about USB, the remaining rule set, current-sense noise, shield return and mechanics still need their own work; they were not relabelled as new discoveries. No thermal, EMC, signal-integrity or hardware qualification was performed.

Evidence: [ordinary DRC](/home/galm/Workspace/KiCad/Pixy-M2/Pixy-M2/layout/review-2026-09-22/drc.json), [physical-hole diagnostic DRC](/home/galm/Workspace/KiCad/Pixy-M2/Pixy-M2/layout/review-2026-09-22/pad-hole-diagnostic-drc.json), [motor-width negative test](/home/galm/Workspace/KiCad/Pixy-M2/Pixy-M2/layout/review-2026-09-22/motor-width-negative-test.json), [per-net measurements](/home/galm/Workspace/KiCad/Pixy-M2/Pixy-M2/layout/review-2026-09-22/measurements.json), [pad-hole distances](/home/galm/Workspace/KiCad/Pixy-M2/Pixy-M2/layout/review-2026-09-22/pad-hole-measurements.json). Current board: 2,309 track segments, 247 vias, 2,431.77 mm total track centreline.

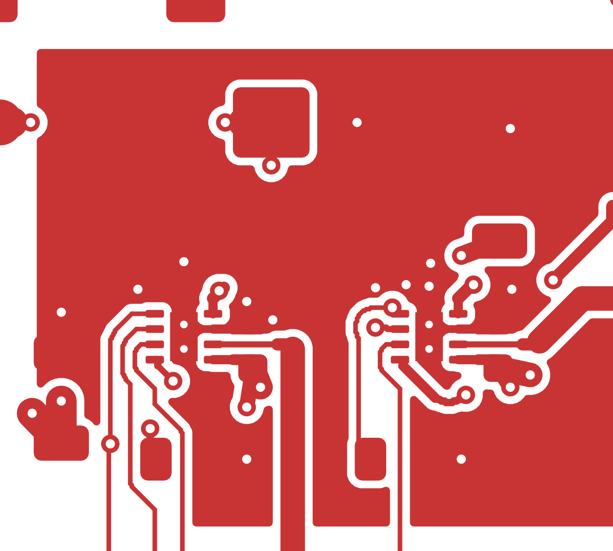
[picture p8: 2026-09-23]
layout/review-2026-09-22/motor-top.png

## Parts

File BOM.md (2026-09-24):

# Pixy-M2 bill of materials — one robot

Extracted from `Pixy-M2.kicad_sch` on 2026-09-23 with `kicad-cli sch export bom`,
after J8/J9 moved to JST SH in the Pololu encoder pin order, then compared with
the board. The PCB has the same 78
footprints and no footprint that is only on the board. This file replaces the
2026-09-19 list. That list predated the motor, IMU and debug blocks, and it still
showed J2/J3 and R3/R4.

Quantities are for **one robot**, with no spares. Imperial package codes are used
(0603, 0805, 1206). **69 parts are fitted to the PCB.** TP1–TP9 are bare 1.5 mm
copper pads, so nothing is bought for them.

Status key: **Fixed** means the part is named in the schematic or design notes.
**Spec** means any part meeting the spec will do. **Open** means the design has
not chosen one yet.

## A. PCB assembly — 69 parts

### Semiconductors

| Qty | Ref | Part | Package | Status |
|---:|---|---|---|---|
| 1 | U1 | Espressif **ESP32-S3-WROOM-1-N16** | module | Fixed. Must be N16, not -R8/-N8R8/-N16R8 (issue 11). |
| 1 | U2 | ST **USBLC6-2SC6** | SOT-23-6 | Fixed |
| 1 | U3 | Diodes Inc **AP63203WU-7** | TSOT-23-6 | Fixed. The fixed 3.3 V variant; do not substitute the adjustable AP63200. |
| 2 | U4, U5 | TI **DRV8231ADSGR** | WSON-8 2×2 | Fixed |
| 1 | Q1 | AOS **AO4407A** | SOIC-8 | Fixed. The symbol is `IRF7404`; do not order that. |
| 2 | D1, D2 | onsemi **MBRA340T3G** | SMA | Fixed |
| 1 | D3 | Vishay **BAT54W-E3-08** | SOD-123 | Fixed as a part. The schematic datasheet link is still Nexperia's, whose BAT54W is SOT-323 and does **not** fit. |
| 1 | D6 | Vishay **SMBJ9.0A-E3/52** | SMB | Fixed |
| 1 | D4 | Red LED, high-efficiency (AlInGaP) | 0805 | Spec. Runs at ~150 µA, so it must be visibly lit at that current. No blue, white or pure-green part (issue 13). |
| 1 | D5 | Green LED | 0805 | Spec. Runs at ~550 µA. |

### Passive power parts, protection and switches

| Qty | Ref | Part | Package | Status |
|---:|---|---|---|---|
| 1 | L1 | Bourns **SRP5030T-4R7M**, 4.7 µH | 5.0×5.0 mm | Fixed (LCSC C2045677) |
| 1 | F1 | Littelfuse **0885005.DR**, 5 A fast-acting fuse, **breaks 1500 A @ 125 VDC** | 885 series, 10.9 × 4.8 × 4.8 mm | Fixed. One-time, not resettable. It replaced the 2920L300/15DR PPTC, which could only break 40 A; this pack can put an estimated 200–400 A into a dead short. |
| 1 | F2 | Bourns **MF-MSMF050-2**, 500 mA hold PPTC | 1812 | Fixed |
| 1 | SW3 | C&K **JS102011SAQN** SPDT slide | SMD | Fixed |
| 2 | SW1, SW2 | E-Switch **TL3301NF160QG** tactile, 160 gf | 6×6 SMD | The footprint is fixed as TL3301N-family. The 160 gf force is a suggestion; 100 gf and 260 gf fit the same footprint. |

### Connectors on the PCB

| Qty | Ref | Part | Status |
|---:|---|---|---|
| 1 | J1 | Amphenol **12401948E412A** USB-C receptacle | Fixed by the footprint. Other USB-C sockets do not fit. |
| 1 | BT1 | AMASS **XT30U-M** (male), vertical in PCB | Fixed by the footprint |
| 7 | J4–J9, J11 | JST **SM06B-SRSS-TB(LF)(SN)**, SH 6-pin side entry | Fixed. J8/J9 are the motor/encoder ports, in Pololu's pin order. |
| 1 | J10 | JST **SM09B-SRSS-TB(LF)(SN)**, SH 9-pin side entry | Fixed |

### Capacitors (MLCC)

Use X7R where it is available; X5R is acceptable for the 10 µF and 22 µF parts.
The voltage ratings are the minimums from issue 8. Do not go lower.

| Qty | Ref | Value | Package |
|---:|---|---|---|
| 5 | C2, C4, C5, C16, C22 | 0.1 µF 16 V | 0603 |
| 2 | C6, C17 | 0.1 µF 25 V | 0603 |
| 4 | C13, C14, C18, C20 | 0.1 µF 50 V | 0603 |
| 1 | C3 | 1 µF 16 V | 0603 |
| 2 | C1, C15 | 10 µF 16 V | 0805 |
| 2 | C7, C11 | 22 µF 16 V | 0805 |
| 3 | C12, C19, C21 | 22 µF 25 V | **1206** |
| 1 | C8 | 4.7 nF **1 kV** | **1206** |

One 0.1 µF 50 V 0603 part can fill all 11 of the 0.1 µF positions. Buying one
reel instead of three is a valid choice.

### Resistors (0805 thick film)

The design requires **1 %** on the eight parts marked 1 %. Buying 1 % for every
position costs nothing extra.

| Qty | Ref | Value |
|---:|---|---|
| 7 | R2, R12, R19–R23 | 10 kΩ |
| 3 | R13, R15, R16 | 2.2 kΩ |
| 2 | R1, R6 | 5.1 kΩ |
| 2 | R17, R18 | 2.2 kΩ **1 %** (motor current limit, 1.0 A) |
| 1 | R5 | 1 MΩ |
| 1 | R7 | 120 kΩ **1 %** |
| 1 | R8 | 24 kΩ **1 %** |
| 1 | R9 | 39 kΩ **1 %** |
| 1 | R10 | 470 kΩ **1 %** |
| 1 | R11 | 220 kΩ **1 %** |
| 1 | R14 | 100 kΩ |

## B. The bare PCB

| Qty | Item | Notes |
|---:|---|---|
| 1 | 4-layer PCB, 1.6 mm, 66 × 100 mm | Use JLC04161H-7628 or an equivalent with ~0.2 mm L1–L2 prepreg. **Order the options below with the PCB:** |
| | • Impedance control on USB D+/D− | 90 Ω differential, 0.25 / 0.15 mm on L1. Otherwise confirm the geometry with the fab's calculator (see "Board stackup"). |
| | • Via fill and cap, IPC-4761 type VII | Only for the four thermal vias under U4/U5. It is recorded on `Dwgs.User`. Tenting is not a substitute. |
| 1 | SMT stencil | Optional, but hard to do without for two 2×2 mm WSON parts with exposed pads. |

## C. Off-board modules

| Qty | Item | Status |
|---:|---|---|
| 4 | **GY-VL53L0XV2** ToF module (silkscreen `HW-842`) | Fixed. J4–J7 copy its header order. A different module needs different cables. |
| 1 | **Adafruit BNO085 9-DoF breakout, #4754** | Fixed. For SPI: wire **P0 to J10.9** (PS0/WAKE) and **tie P1 to VIN** at the module end. SCL is SCK, SDA is MISO and DI is MOSI (Adafruit's pin names). |
| 2 | **Pololu Micro Metal Gearmotor HP 6V with 12 CPR encoder** (#5153–#5165 series, extended shaft, encoder fitted) | **Ratio open.** Pick one ratio for both motors, e.g. #5155 (10:1) or #5157 (15:1). The side- and back-connector versions have the same pinout. Either encoder version stands 3–4 mm proud of one face of the motor. **Mount each motor with that face outboard (A forward, B rearward) or toward the floor:** the battery sits 1.5 mm from their inboard faces. |
| 1 pack (listing is 4) | **OVONIC 2S 450 mAh 100C, XT30** ([Amazon B0D2KT723L](https://www.amazon.com/gp/product/B0D2KT723L)) | Chosen. The maker lists it at 7.4 V / 4.2 V per cell (standard LiPo, not LiHV, despite "High Voltage" in the title), **62 × 17 × 14 mm, 31 g**, XT30 female, JST-XH balance lead. XT30 female is the battery-side part, so it mates with BT1 (male). **See "Battery" below: it goes across the underside between the motors, and F1 was changed to interrupt its fault current.** |

## D. Cables and crimp parts

Hand-crimped JST is fiddly. Pre-crimped single-ended "SH 6-pin" leads
with bare wire, avoid most of the crimping.

| Qty | Cable | Board end | Far end |
|---:|---|---|---|
| 4 | ToF, 6-way, straight 1:1 | SHR-06V-S-B + 6 × SSH-003T-P0.2-H | 6-way 2.54 mm Dupont socket, or solder to the module |
| 1 | IMU, 9-way | SHR-09V-S-B + 9 × SSH-003T-P0.2-H | Dupont sockets or solder, wired per the J10 table in CLAUDE.md |
| 2 | Motor/encoder | **Pololu JST SH-style encoder cable, female-female**, straight 1:1: #4765 (10 cm), #4766 (16 cm), #4767 (25 cm), #4768 (40 cm) or #4769 (63 cm) | Ready-made, so no crimping. Both ends are SH, so it plugs straight into J8/J9. |
| 1 | Debug (optional) | SHR-06V-S-B + 6 × SSH-003T-P0.2-H | a 3.3 V USB-UART adapter with DTR/RTS |

Crimp totals, including the debug lead: **5 × SHR-06V-S-B**, **1 × SHR-09V-S-B** and
**39 × SSH-003T-P0.2-H**. Buy about 2× the contacts, because hand crimping loses
some. Also needed: 28–32 AWG wire.

### J8/J9 and the Pololu motors

J8/J9 now use the Pololu encoder board's own connector and pin order (checked on
[#5161](https://www.pololu.com/product/5161) and the cable page
[#4766](https://www.pololu.com/product/4766)):

| pin | 1 | 2 | 3 | 4 | 5 | 6 | MP |
|---|---|---|---|---|---|---|---|
| encoder / J8 / J9 | GND | OUT B | OUT A | VCC (3.3 V) | M2 | M1 | GND |
| Pololu cable wire | green | white | yellow | blue | black | red | — |

Pololu's cable is straight 1:1, so it plugs in either way round with no
re-pinning. Pololu rates these contacts and cables at **1 A**, so **R17/R18 are
now 2.2 kΩ**. That puts the DRV8231A's current limit at 1.00 A, down from 1.47 A,
and still gives about 63 % of the motor's 6 V stall torque. IPROPI now reads
3.3 V/A, so the ADC clips at about 0.94 A, just below the limit.

### Battery

- **Where it goes (2026-09-24).** Across the underside, between the two
  motors: board X 0.5–62.5, Y 57.5–74.5, wide face on the board, with its
  leads at the +X (right-hand) end. Its centre is on the rotation centre's Y.
  The listing gives 61.5 × 15.77 × 13.48 mm and the maker 62 × 17 × 14 mm, so
  the bay is drawn at the larger size, 1.5 mm from each motor body. The front
  strip also fits, but it puts the robot's CG about 6 mm ahead of the front
  axle. The underside silkscreen shows the outline, the lead end and the
  lead's route. See CLAUDE.md, "Battery between the axles".
- **Fixing.** Hook-and-loop tape on the pack's top face. The drive lanes beside
  it leave no path for a strap.
- **Lead.** The XT30 and balance leads leave the +X end and run forward on the
  underside along X = 64.5. They cross the front strip at Y = 29.5 and wrap the
  left edge between J6 and BT1. From the pack to the back of the XT30 plug that
  is **about 13 cm**. If the pack's own lead is shorter, add an XT30
  extension (below) or re-lead the pack.
- **Fault current — handled by F1.** The pack is sold as 100C continuous and
  200C burst (45 A and 90 A), and its dead-short current is estimated at
  200–400 A. The original F1 PPTC could break only 40 A. Rather than give up the
  burst current with a lower-C pack, F1 is now a Littelfuse 0885005.DR rated to
  break 1500 A.
- **Charging.** You need a 2S balance charger with an XT30 lead (or an adapter)
  and a JST-XH balance port.

## E. Mechanical — not designed yet

This section is **not definitive**. `layout/README.md` gives only space
reservations: "idlers, axle supports and gear ratios remain unspecified". Nothing
here can be ordered from the repo until the drivetrain is designed.

| Qty | Item | Constraint from the layout |
|---:|---|---|
| 2 | Wheels, Ø30 mm, ≤ 8 mm tire | They must fit the motor's 3 mm D-shaft or a drivetrain axle |
| 2 | Micro metal gearmotor brackets | 38 × 16 × 16 mm underside envelopes. **Outboard side only:** the battery fills the space between the motors, so nothing may clamp or fasten on their inboard faces. |
| ? | Gears, idlers, axles, bearings | Undefined. The motors are staggered at Y = 50 / 82 and are not coaxial with the wheels. |
| 4 | Sensor brackets | 14 × 19 mm mounts. J6/J7 are aimed 45° ± 15°. |
| 1 | IMU standoff or bracket | 25 × 25 mm at the rotation centre |
| — | Fasteners | **The PCB has no mounting holes**; the attachment method is open |
| 1 | Hook-and-loop tape, ~60 × 15 mm | Holds the battery to the underside between the motors |
| 1 | XT30 male-to-female extension, 10–15 cm | Only if the pack's lead is shorter than the ~13 cm route to BT1 |

## F. Tools and consumables (if you don't already have them)

2S LiPo balance charger (XT30, JST-XH balance) · JST SH crimp tool · solder paste and a hot-air or
reflow setup (the WSON exposed pads and the module's ground pads need it) · 3.3 V USB-UART adapter (only
for J11).

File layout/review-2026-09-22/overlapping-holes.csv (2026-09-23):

reference | pad | via_x_mm | via_y_mm | net | overlap_mm | intentional_thermal | via_uuid
Q1 | 6 | 126.5 | 97.9 | /VBAT | 0.069295 | False | f361ec2d-b5ad-47bb-a443-94baeabc5fb3
Q1 | 7 | 126.5 | 96.65 | /VBAT | 0.058701 | False | fc3b3d47-fa03-4af4-861a-1e28c2427cbd
Q1 | 8 | 126.5 | 95.35 | /VBAT | 0.074113 | False | ab708dbc-8dd8-416a-846e-bb9a9d5d8446
R22 | 2 | 157.4 | 111.7 | /GPIO38 | 0.046447 | False | a2b8e854-cfe6-438b-8280-96d3a7158328
U1 | 41 | 133.6 | 149.15 | GND | 0.1 | False | a6f07216-ad4e-440b-a22e-94b2d62c2f30
U1 | 41 | 133.6 | 150.55 | GND | 0.1 | False | e09a10a6-4b77-4421-86af-a3aba1bd4bcb
U1 | 41 | 133.6 | 151.95 | GND | 0.1 | False | 2517cbc7-96df-4745-b377-24b83bacbd58
U1 | 41 | 135.0 | 149.15 | GND | 0.1 | False | 6ee3ea6a-95aa-4aa6-94c4-2416264c22d3
U1 | 41 | 135.0 | 150.55 | GND | 0.1 | False | 10af4f5b-b0d5-4f25-b26f-698b5b0fe343
U1 | 41 | 135.0 | 151.95 | GND | 0.1 | False | 28d342de-9384-4d80-b4c6-c7a2191b8e7e
U1 | 41 | 135.55 | 149.95 | GND | 0.01 | False | 99090151-3f34-497c-8aa3-d5690ac10b32
U4 | 9 | 109.0 | 113.6 | GND | 0.525 | True | 4fe049ba-90b9-48f1-bfdb-6e0ec3a1be9b
U4 | 9 | 109.0 | 114.4 | GND | 0.525 | True | 5becb970-c00c-44fe-b7d3-f59363c3fb1a
U5 | 1 | 115.8 | 113.05 | /GPIO10 | 0.074433 | False | e19afae7-02ad-43e7-926c-98cf34dffeba
U5 | 9 | 117.0 | 113.6 | GND | 0.525 | True | 6e8f5fd1-19f8-4116-b1e7-805ae8beffcb
U5 | 9 | 117.0 | 114.4 | GND | 0.525 | True | cf1c110c-ee1e-4e92-a19a-54d75ef9f53e

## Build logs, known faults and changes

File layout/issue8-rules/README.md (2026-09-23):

# Issue 8 — the rule set encodes the routing requirements — 2026-09-22

REVIEW.md finding 8: the project had only the Default netclass, no netclass
assignments and a global 0.15 mm minimum track width. Nothing stopped narrow
copper on motor, USB or supply paths. The motor part was closed with finding 1
(`Motor` netclass and trunk rule), and the USB part with finding 7 (`USB`
netclass, width, layer and coupling rules). This pass covers the rest:

- the general signal minimum;
- the supply paths;
- the "keep away" constraints in CLAUDE.md.

Turning the rules on exposed real copper that failed them, and that copper was
fixed in the same pass.

## Rules added

`Pixy-M2.kicad_pro` adds two netclasses:

| class | nets | default width |
|---|---|---:|
| `Battery` | `/VBAT_RAW`, `/VBAT_FUSED` | 1.0 mm |
| `Power` | `/VBUS`, `/VSYS`, `Net-(F2-Pad1)` | 0.6 mm |

`Pixy-M2.kicad_dru` adds these rules:

| rule | constraint | exception |
|---|---|---|
| Signal minimum width | every track ≥ 0.2 mm | inside the `Motor pin escape` areas (DRV8231A pin fields) |
| Power path width | `Power` ≥ 0.5 mm | inside the new `Power pin escape` area (U2's VBUS pin, which leaves under the package) |
| Battery path width | `Battery` ≥ 0.8 mm | none |
| REG_EN clear of the switch node | ≥ 0.35 mm to `U3-SW`/`U3-BST` | — |
| Sense nodes clear of motor and switch copper | `REG_EN` ≥ 5 mm to motor copper. `VBAT_SENSE` ≥ 5 mm to motor, SW and BST copper | — |
| IPROPI clear of motor outputs | `GPIO2`/`GPIO10` ≥ 0.25 mm to motor copper | — |

Three KiCad behaviours shaped how these are written. All three were checked,
not assumed:

- **Board-setup minimums are absolute.** A custom rule cannot relax them. With
  the board minimum raised to 0.2 mm, a 0.15 mm rule inside the pin-field areas
  was ignored. So the board floor stays 0.15 mm, the pin fields' need, and a
  custom rule raises everything else.
- **When two rules set the same constraint, the later one wins.** The generic
  0.2 mm rule is therefore the *first* rule in the file. The motor, USB, power
  and battery rules below it still override it; see the motor case in the
  negative tests.
- **`enclosedByArea` tests the whole track outline, round caps included.** A
  segment clipped exactly at an area edge pokes out by half its width. The
  widening clips at the areas shrunk by 0.1 mm.

`/VBAT` is in neither supply class, deliberately. Its current runs in the In2
island. Its tracks are stubs from pads to plane vias, and the pin pitch sets
their width, not the current.

The clearance rules are **floors set just under what the board achieves**. They
stop erosion; they do not certify the constraint. Two are well below what
CLAUDE.md asks for, and are recorded as such rather than hidden:

- **REG_EN**: 0.40 mm. U3's EN via under the package sits 0.40 mm from the SW
  pin. The standing fix is to re-place R8/C13 next to U3.2.
- **IPROPI**: 0.29 mm. A GPIO2 via sits beside a MOT_A_2 B.Cu trunk near U4.
  Validate the current reading on hardware.

## Copper the rules required (`tools/autoroute/issue8.py`)

The stage runs in `rework.py` straight after `usb_pair.py`.

| | before | after |
|---|---:|---:|
| track narrower than 0.2 mm | 219.4 mm, on five nets end to end | **8.7 mm**, all inside the DRV8231A pin fields |
| `/VBUS` F2 → D1 | 50.7 mm at 0.24 mm, **105.4 mΩ** | 0.6 mm, **44.4 mΩ** |
| USB input J1.A9 → F2 | 0.24 mm, 9.7 mΩ | 0.6 mm, 4.0 mΩ |
| USB input J1.A4 → F2 | 0.2–0.25 mm, 32.7 mΩ | 0.6 mm, 8.2 mΩ |
| `/VBAT_FUSED` R14 tap | 0.2 mm | 0.8 mm |
| vias | 243 | 243 |

Resistance is DC at 20 °C in 35 µm copper, from `measure.py`. At F2's 0.5 A hold
current the VBUS run drops 22 mV instead of 53 mV.

- **Signals.** `GPIO39/40/41` (motor IN1/IN2) and `GPIO2/10` (IPROPI) had been
  routed at 0.15 mm for their whole 40–52 mm, because the router used one width
  per net. They are now 0.2 mm everywhere outside the pin fields. B.Cu copper
  under the drivers had room, so it is 0.2 mm too. One GPIO41 corner doglegs
  0.3 mm to clear the GPIO47 via issue 6 moved beside it; widened in place it
  would have been 0.18 mm from that via.
- **USB supply.** It carries the whole board on USB. `CLAUDE.md`'s width table
  said 0.6 mm; the copper was 0.24 mm. It is now re-routed at 0.6 mm:
  - The D3 tap (VBUS → D3 → R9 → REG_EN) is 0.5 mm, pinned by F.Cu waypoints
    to its old corridor along the top edge. Unpinned, A* sent it through the
    buck block, 0.5 mm from C6's switch-node pad, straight into the enable
    divider.
  - The pinning found a bug in `Router.route_waypoints`: it offers each
    waypoint on both layers, so consecutive legs can meet on different layers
    with no via. Its only existing caller, the MOT_B_2 pairing, happens not to
    trigger it. `issue8.py` routes its own legs instead.
- **Vias near pads.** The router bars via *centres* from 0.15 mm round a pad. A
  0.3 mm drill can then touch the mask opening; it missed by 0.04 mm at both
  J1 VBUS pads on the first try. For this stage only, the bar is drill
  radius + 0.10 mm + one grid step, matching issue 6's floor. Earlier stages
  keep the old bar so they replay unchanged.

## Validation

- **DRC.** `--schematic-parity --refill-zones` gives 0 unconnected and 0 parity
  issues (`drc.json`). The only violations are the four pre-existing J1
  `hole_clearance` errors and the U1 `lib_footprint_mismatch` warning, the same
  verdict as before.
- **Aperture audit.** `via_openings.py`: 0 violations, 243 vias, 0.10 mm
  minimum (`aperture-audit.json`).
- **Negative tests.** `negative-tests.json` has one deliberately broken copy
  per rule, and each rule fires:

  | case | edit | fires |
  |---|---|---|
  | signal | a GPIO21 segment at 0.15 mm | Signal minimum width |
  | motor | a MOT_B_1 trunk at 0.4 mm | Motor trunk minimum width (still wins over the generic rule) |
  | usb | a USB_D+ segment at 0.2 mm | USB line width and pair gap |
  | power | a VBUS run at 0.3 mm | Power path width |
  | battery | a VBAT_FUSED trunk at 0.6 mm | Battery path width |
  | reg_en | the EN via 0.1 mm closer to SW | REG_EN clear of the switch node |
  | ipropi | the GPIO2 via 0.06 mm closer to MOT_A_2 | IPROPI clear of motor outputs |
- **Nothing else moved.** A track/via diff against the issue-7 board touches
  only `GPIO2/10/39/40/41`, `/VBUS`, `Net-(F2-Pad1)` and `/VBAT_FUSED`.
  - Motor, USB, buck and issue-6 copper are unchanged.
  - Motor loops are unchanged at 103.3 / 83.4 mm².
  - Exact clearances before and after (`clearances.json`, `clearmin.py`) are
    identical. VBUS/VSYS copper stays 1.11 mm from the switch node, the
    spacing U3's own pins set, so the new supply routes come no closer to it.
- **Replay.** A full `rework.py` replay reproduces the board exactly.

Figures: `supply-top-before.png` / `supply-top.png` (D1, the D3 tap, the buck
block) and `supply-connector.png` (J1 → F2).

## Corrections to earlier notes

- CLAUDE.md issue 5 said `REG_EN` copper passes **0.99 mm** from switching
  copper. Measured exactly, it is **0.40 mm**, from the EN via to the SW pin.
- The first measurement in this pass used a single 20 mm DRC threshold. It
  reported 0.95 mm for REG_EN and 0.75 mm for IPROPI, both wrong; see
  `clearmin.py`.

## Not done

- `REG_EN` and IPROPI are not moved; see above.
- D6's single ground via and narrow VBAT stub (a REVIEW.md side observation) are
  untouched. The width rule does not cover `/VBAT`.

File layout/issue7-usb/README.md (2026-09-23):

# Issue 7 — USB routed as a coupled pair — 2026-09-22

REVIEW.md finding 7: USB D+/D− were ordinary 0.2 mm traces with varying
separation, a D+ detour around U2, and D− changing to B.Cu and back through
vias while D+ stayed on F.Cu. The 2026-09-22 audit found the issue-6 via pass
had made D− worse (4 vias, 8 mm on B.Cu).

Both polarities now run as one pair from J1 to U1, on F.Cu over the In1 ground
plane, with **no vias anywhere on the USB path**.

## What changed

- **U2 turned 90°**, (154, 148) rot 0 → (153.5, 149.5) rot 90. USBLC6-2SC6
  carries each line in on one side of the package and out of the other. At
  rot 0 that ran west→east while the signal runs J1 (south) → U1 (north-west),
  so D+ had to wrap round the package. At rot 90 the connector pins (1, 2, 3)
  face J1 and the module pins (6, 5, 4) face U1, with D− on the west in both
  rows. The pair goes straight through the part and never crosses itself.
- **U2's middle pins leave under the body**, through the 1 mm gap between the
  pin rows, so neither crosses the pair. GND (2) goes to a plane via under the
  package, 0.71 mm of copper from the pin; the old return was 1.11 mm. VBUS (5)
  goes east to the existing feed from F2.
- **J1's alternating pads** (B7 D−, A6 D+, A7 D−, B6 D+) are joined on F.Cu:
  a D+ bridge over the top of A7 and a D− loop under the bottom of A6. The old
  D− loop used a via to B.Cu. Both joins are short stubs, about 1.4 mm each.
- **The pair**: 0.25 mm lines with a 0.15 mm gap, 13.75 mm coupled on the module
  side. It splits only where U2's 1.9 mm pin pitch and U1's 1.27 mm pitch force
  it to.
- **CC1/CC2 re-routed** around the pair by the A* router. They were ripped
  because their vias sat where the pair now runs. They cross under the pair on
  B.Cu, with the In1 plane between. The router kept their F.Cu copper and vias
  an extra 0.15 mm off the pair, except in J1's pad field.
- **Silkscreen**: U2's reference sits upright east of its module-side pins. J1's
  reference was moved off U2's connector-side pins.

The stage is `tools/autoroute/usb_pair.py`, run by `rework.py` after the
issue-6 via repairs. Nothing earlier in the replay changes.

## Impedance

`tools/impedance/zdiff.py` is a 2D field solver for the odd mode of
edge-coupled microstrip with conformal solder mask. It was run against this
board's F.Cu → In1 stackup: 35 µm copper on 7628 prepreg with εr 4.4. KiCad's
stackup uses 0.200 mm prepreg; JLCPCB's JLC04161H-7628 quotes 0.2104 mm. Mask
is 10–25 µm with εr 3.8. For 0.25 / 0.15 mm the results are:

| prepreg | mask 10 µm | mask 25 µm |
|---|---:|---:|
| 0.200 mm | 93.0 Ω | 89.5 Ω |
| 0.2104 mm | 94.2 Ω | 90.6 Ω |

At a 5 µm mesh the solver reads about 1.5 Ω high against 2.5 µm (91.5 Ω for the
first cell). The IPC-2141 closed form gives 90.4 Ω with no mask. The spread
across stackup, mask and method is **about 88–94 Ω**, inside Espressif's
90 Ω ± 10 % (81–99 Ω). **This is a calculation, not a fabricator figure:**
confirm with JLCPCB's impedance calculator, or order impedance control, before
fabrication. Raw output: `impedance.txt`.

## Measurements (`measurements.json`, from `measure.py`)

Before is commit `0c70856`; after is this board.

| | before | after |
|---|---:|---:|
| USB vias | 4 (all on D−) | **0** |
| USB copper on B.Cu | 8.01 mm | **0** |
| line width | 0.20 mm | **0.25 mm** |
| end-to-end path, J1 pad → U2 → U1 pad: D+ / D− | 24.54 / 32.62 mm | **20.15 / 19.11 mm** |
| end-to-end skew | 8.08 mm | **1.04 mm** (≈ 6 ps) |
| module-side pair gap | 0.25–0.35 mm | **0.15 mm** coupled |
| closest other-net F.Cu copper to a USB line | 0.22 mm (VBUS) | 0.275 mm (CC1, in J1's pad field) |
| board vias | 247 | 243 |
| CC1 / CC2 track | 4.92 / 13.57 mm | 5.81 / 8.53 mm |

The remaining 1.04 mm of skew comes from the pair's two 45° bends, where D− is
the inner line, and from D+'s climb into U1 pin 14. It is below the 1.25 mm
(50 mil) figure commonly used as a *High* Speed matching target. The ESP32-S3
PHY is Full Speed only.

The connector-side pair is 1.13 mm coupled at 0.25 mm. That spacing is J1's
0.5 mm pad pitch, not a routing choice.

## Rules

- `Pixy-M2.kicad_pro` has a new **`USB` netclass**: 0.25 mm width, 0.15 mm
  diff-pair gap, 0.15 mm clearance *within* the class. Clearance to every other
  net stays 0.2 mm. It is matched by `/USB_D*` and `Net-(J1-D*`.
- `Pixy-M2.kicad_dru` gains three rules:
  - USB line width must be 0.24–0.26 mm.
  - USB nets may not have tracks or vias on B.Cu.
  - For `/USB_D±`, the pair gap must be 0.14–0.16 mm and no more than 4 mm may
    be uncoupled. As routed, 3.4 mm is uncoupled, forced by the two pin pitches.
- KiCad treats only `/USB_D+` / `/USB_D-` as a differential pair, because the
  connector-side net names do not end in ±. The coupling rule therefore covers
  the module side only. The width and layer rules cover all four nets.
- **Negative test** (`negative-tests.json`). Each case is a deliberately broken
  copy, and each rule fires:
  - A 0.20 mm segment raises `track_width`.
  - The J1 D− loop moved to B.Cu raises `items_not_allowed`.
  - A /USB_D− segment moved 0.10 mm away raises `diff_pair_gap_out_of_range`.

## Validation

- `kicad-cli pcb drc --schematic-parity --refill-zones` shows 0 unconnected
  items and 0 parity issues (`drc.json`). The only violations are the four
  pre-existing J1 `hole_clearance` errors and the U1 `lib_footprint_mismatch`
  warning, the same verdict as before this change.
- `via_openings.py` reports 0 violations, 243 vias, a 0.10 mm minimum
  ordinary gap, and 0 unintended overlaps (`aperture-audit.json`).
  `test_via_openings.py` passes.
- **Nothing else moved.** A track/via diff against `0c70856` touches only these
  nets: the four USB nets, CC1, CC2, U2's GND stub and via, and U2's VBUS
  fan-in. Every motor, buck, encoder and issue-6 via is byte-for-byte the same
  geometry. Motor loop areas are unchanged at 103.3 / 83.4 mm² (`loop.py`).
- A full `rework.py` replay from `base-routed.kicad_pcb` reproduces this board
  exactly. It also reproduced `0c70856` exactly before the USB stage was added.

Figures: `usb-before.png`, `usb-after.png` (F.Cu red, B.Cu blue, silkscreen
black).

## Not done here

- The **shield return** (J1 shell → C8/R5), which REVIEW.md lists as a separate
  observation, still takes its long B.Cu path behind U2. It is untouched.
- No signal-integrity simulation or hardware eye measurement was performed.

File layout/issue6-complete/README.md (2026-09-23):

# Issue 6 completed — 2026-09-22

The earlier repair checked via centres, leaving 12 ordinary holes overlapping
pad openings. Another 23 vias had less than 0.10 mm edge clearance. This pass
moves all 35 locally: **zero unintended overlaps, 0.10 mm minimum clearance**
to every front/back pad mask and paste aperture.

All 2,228 existing track segments and all footprints are retained. There are
48 short connection segments (11.20 mm total); the via count stays at 247 and
all drill/diameter/net assignments are unchanged. The longest via move is
1.814 mm at R19 (GPIO47). The completed P3 GPIO48 route, USB traces, motor-output
trunks and local driver bypass tracks are unchanged.

The four 0.45/0.25 mm GND thermal vias under U4/U5 have **per-via filling and
capping enabled**, verified after saving/reopening. They remain under the
independent paste apertures. The drawing requires resin fill and copper cap,
IPC-4761 type VII; include this process in the fabrication order. Board-wide
fill/cap settings remain off. KiCad supports these settings per via; the earlier
note saying otherwise was incorrect. See the [KiCad 10 via documentation](https://docs.kicad.org/10.0/en/pcbnew/pcbnew.html)
and [JLCPCB via-covering guide](https://jlcpcb.com/help/article/pcb-via-covering).

The 0.10 mm clearance is this board's design allowance, not a manufacturer rule.
The new `Via drill to solder pad` DRC rule checks physical hole clearance even
on the same net. Its exception is limited to the specified thermal vias and
their own exposed-pad apertures. `via_openings.py` separately checks the actual
mask/paste shapes, includes unnumbered paste-only pads, and verifies fill/cap.

Validation:

- Final KiCad DRC after refilling and saving: zero unconnected items and zero
  schematic-parity issues; only the existing four J1 hole-clearance errors and
  U1 library-footprint warning remain. No new DRC violations.
- The new rule reports 36 additional violations on the prior board (including
  duplicate pad geometries) and none on the repaired board.
- Five regression tests pass: outside-centre drill overlap, tangency, rotated
  pads, rounded/oval pads, and paste-only apertures with mandatory fill/cap.
- The local repair replays to identical track/via geometry and is idempotent.
  The complete `rework.py` pass also reproduces the saved track/via geometry and
  footprint/pad geometry, and its final aperture audit passes.
- Native KiCad copper exports inspected for U1, Q1, the drivers and buck stage.

Files: `validation.json` records PCB hashes and preservation checks;
`aperture-audit.json` records nearest aperture clearance for every via;
`via-moves.csv` lists all moves; `drc.json` is the final KiCad report.

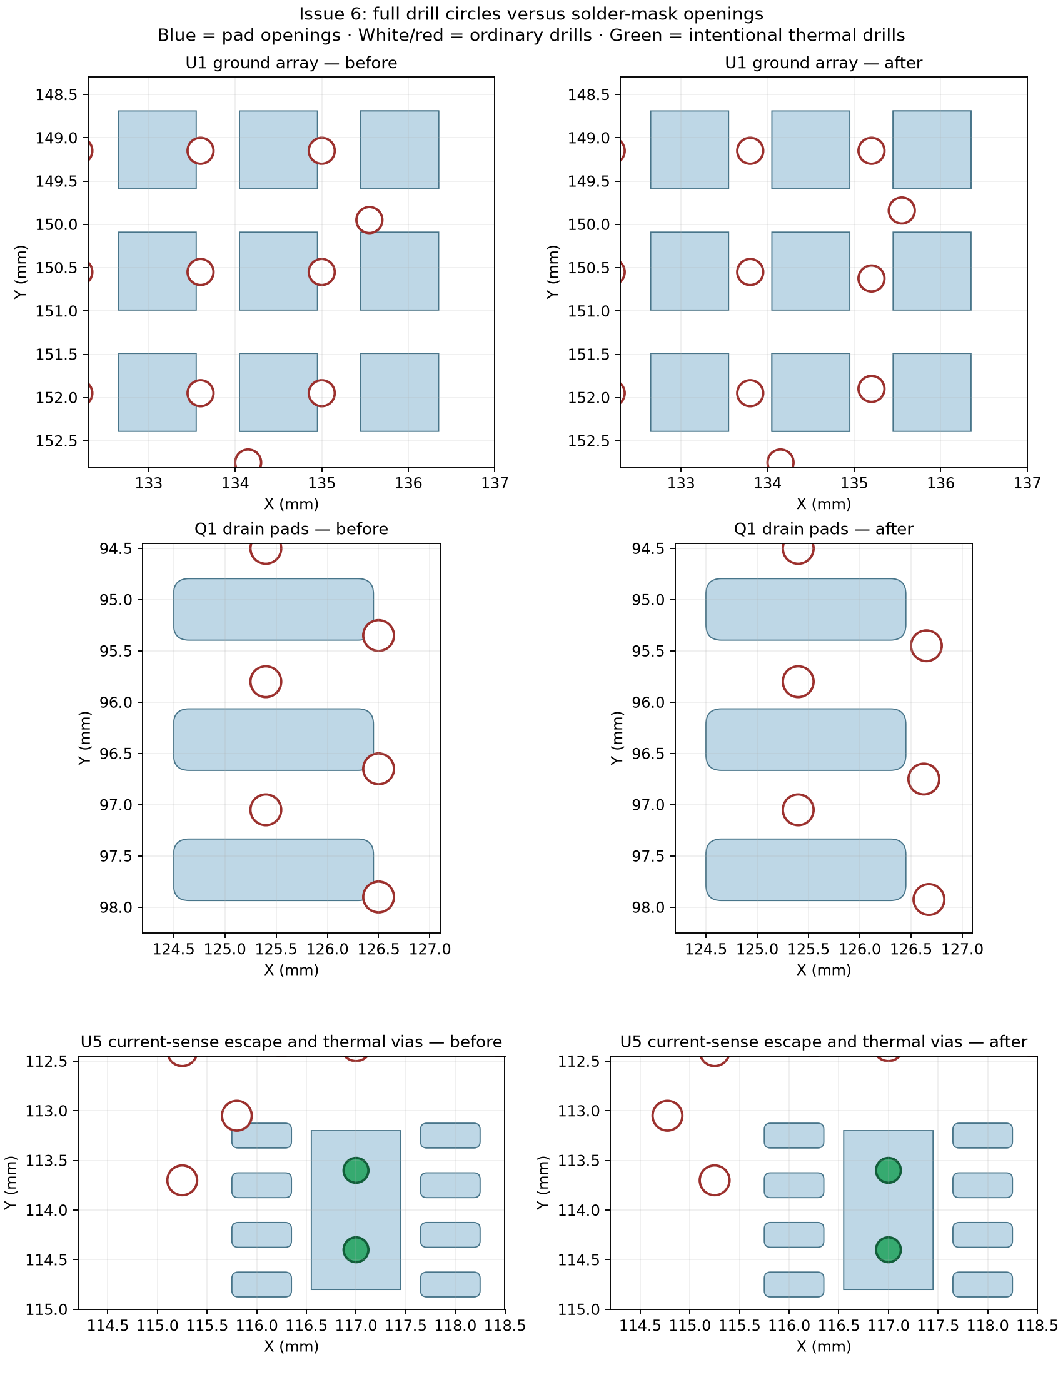
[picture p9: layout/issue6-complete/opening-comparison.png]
Drill openings before and after


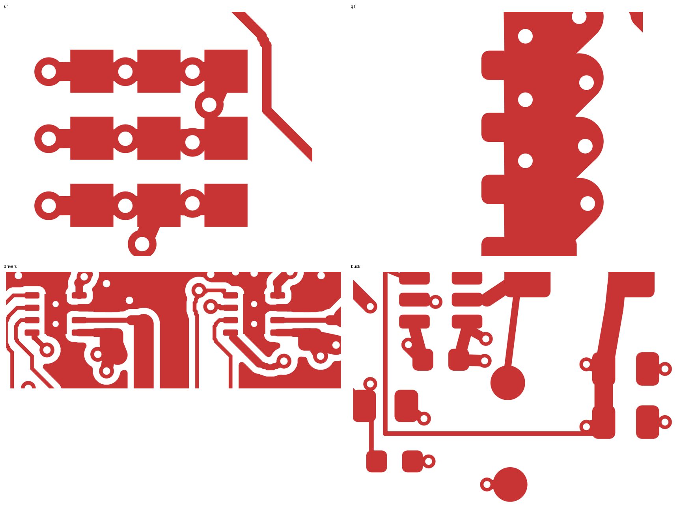
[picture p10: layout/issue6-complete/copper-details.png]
Native KiCad copper detail plots


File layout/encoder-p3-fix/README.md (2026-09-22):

**Encoder detour cleanup — audit P3, 2026-09-22**

GPIO48 now takes a local route between J8.4, R20.2 and U1.25. Its total track
length falls from **72.36 mm to 26.03 mm (64% shorter)**, removing the excursion
around TP5 and J11. The route uses 0.2 mm tracks and four 0.6/0.3 mm vias. All
four drill edges are at least **0.45 mm clear of SMD solder-mask openings**.

The J8-to-R20 branch and U1 pad escape were retained; a short bridge above R20
reaches the bottom-layer corridor alongside GPIO47. Component positions, pad
geometry and every other net's tracks and vias are unchanged. Copper zones were
refilled after the edit.

`encoder48_cleanup()` in `tools/autoroute/rework.py` reproduces the verified route
after the generic via relocation pass, so regeneration does not restore the
detour. Its generated geometry was checked against the validated board.

Fresh KiCad 10.0.5 DRC with zone refill and schematic parity reports **zero
unconnected items, zero schematic mismatches and zero new violations**. The
existing four J1 hole-clearance reports and U1 library-footprint warning remain.
This closes the layout concern in P3; it is not a hardware encoder-noise test.

[Route illustration](/home/galm/Workspace/KiCad/Pixy-M2/Pixy-M2/layout/encoder-p3-fix/encoder-after.png)
· [DRC report](/home/galm/Workspace/KiCad/Pixy-M2/Pixy-M2/layout/encoder-p3-fix/drc.json)
· [Measurements and scope checks](/home/galm/Workspace/KiCad/Pixy-M2/Pixy-M2/layout/encoder-p3-fix/validation.json)

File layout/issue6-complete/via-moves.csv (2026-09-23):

net | old_x_mm | old_y_mm | new_x_mm | new_y_mm | displacement_mm
/VBAT | 111.5 | 115.65 | 110.7 | 115.625 | 0.800391
/VBAT | 126.5 | 95.35 | 126.65 | 95.45 | 0.180278
/VBAT | 119.65 | 115.65 | 119.675 | 115.7 | 0.055902
/VBAT | 126.5 | 97.9 | 126.675 | 97.925 | 0.176777
/VBAT | 126.5 | 96.65 | 126.625 | 96.75 | 0.160078
/REG_EN | 138.7 | 96.1 | 138.775 | 96.1 | 0.075
/REG_EN | 135.95 | 99.7 | 135.95 | 99.65 | 0.05
/ESP_3V3 | 145.4 | 98.8 | 145.3 | 98.8 | 0.1
/ESP_3V3 | 145.4 | 101.5 | 145.3 | 101.5 | 0.1
GND | 141.1 | 104.0 | 141.0 | 104.0 | 0.1
GND | 135.0 | 150.55 | 135.2 | 150.625 | 0.2136
GND | 133.6 | 151.95 | 133.8 | 151.95 | 0.2
GND | 135.0 | 151.95 | 135.2 | 151.9 | 0.206155
GND | 138.4 | 103.0 | 138.475 | 103.0 | 0.075
GND | 148.6 | 99.0 | 148.7 | 99.0 | 0.1
GND | 111.9 | 113.45 | 111.975 | 113.45 | 0.075
GND | 135.0 | 149.15 | 135.2 | 149.15 | 0.2
GND | 138.2 | 101.15 | 138.275 | 101.15 | 0.075
GND | 135.55 | 149.95 | 135.55 | 149.84 | 0.11
GND | 133.6 | 149.15 | 133.8 | 149.15 | 0.2
GND | 148.6 | 101.3 | 148.7 | 101.3 | 0.1
GND | 119.65 | 107.2 | 119.7 | 107.1 | 0.111803
GND | 111.05 | 112.85 | 111.05 | 112.775 | 0.075
GND | 133.6 | 150.55 | 133.8 | 150.55 | 0.2
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

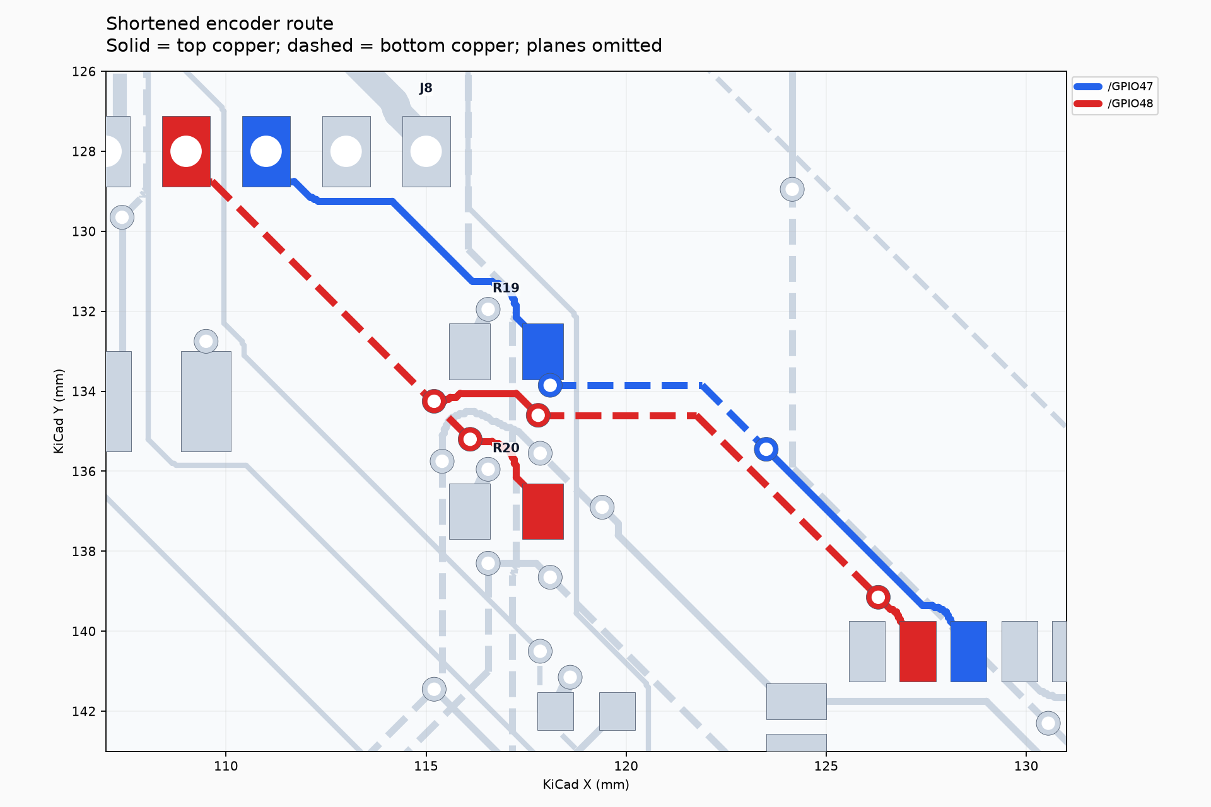
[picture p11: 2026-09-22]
layout/encoder-p3-fix/encoder-after.png

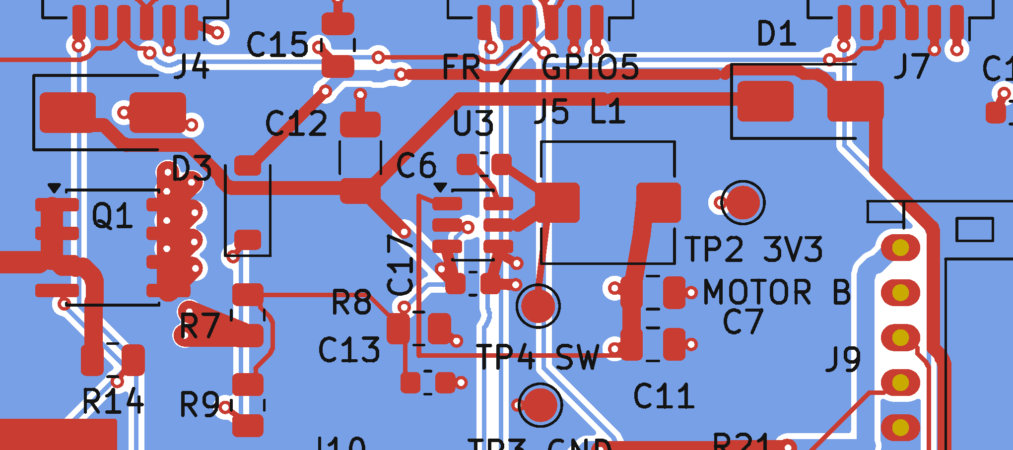
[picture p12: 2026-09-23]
layout/issue8-rules/supply-top.png

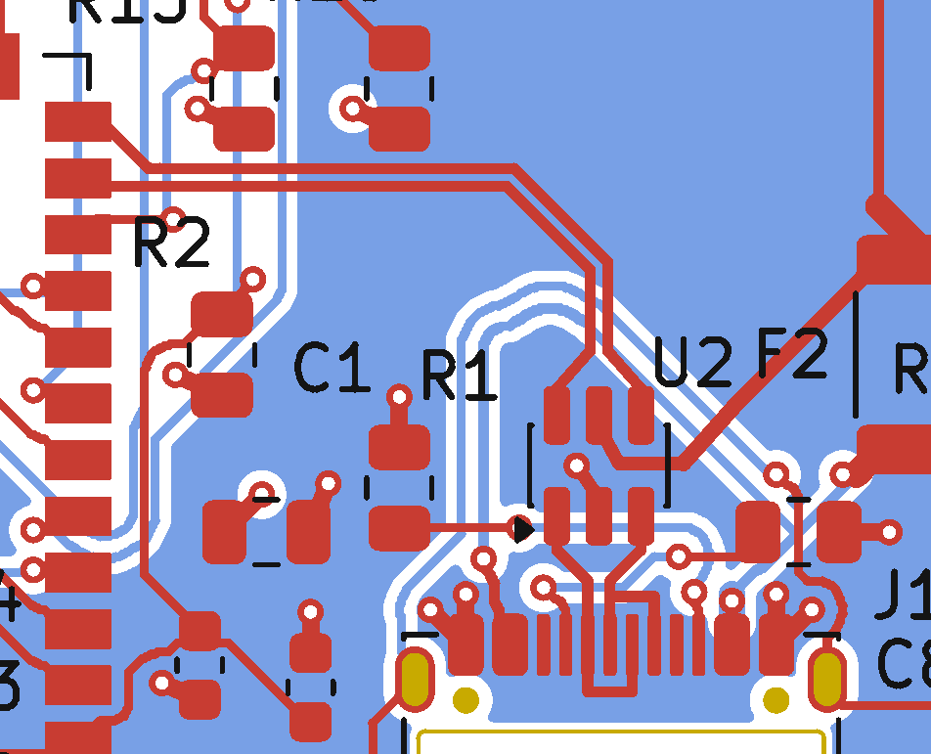
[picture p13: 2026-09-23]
layout/issue7-usb/usb-after.png

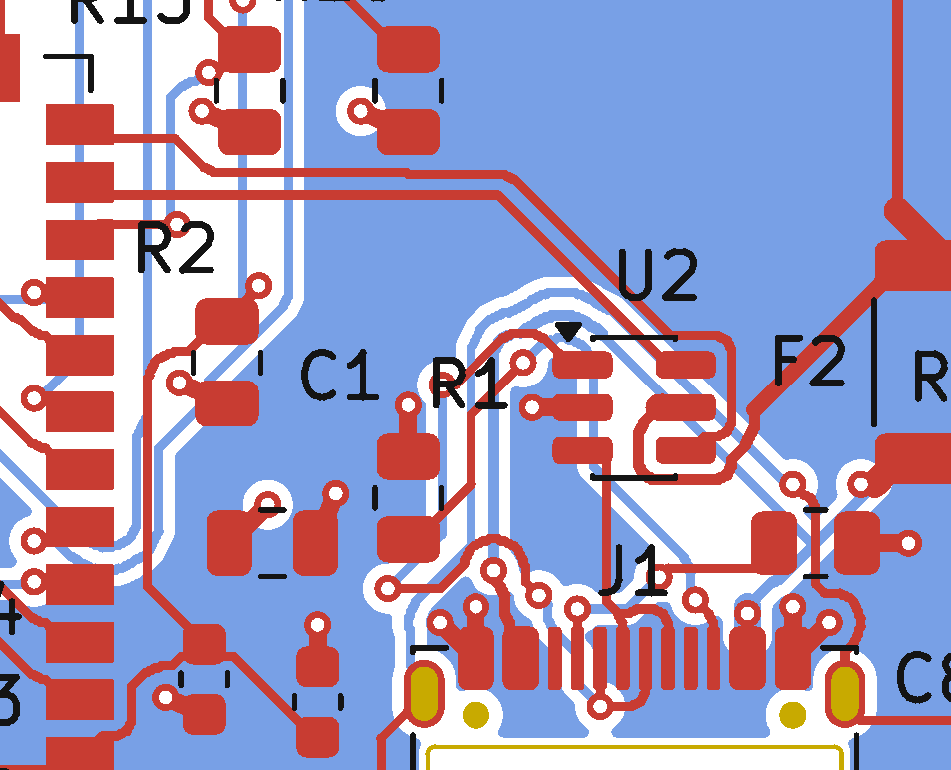
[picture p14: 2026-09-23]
layout/issue7-usb/usb-before.png

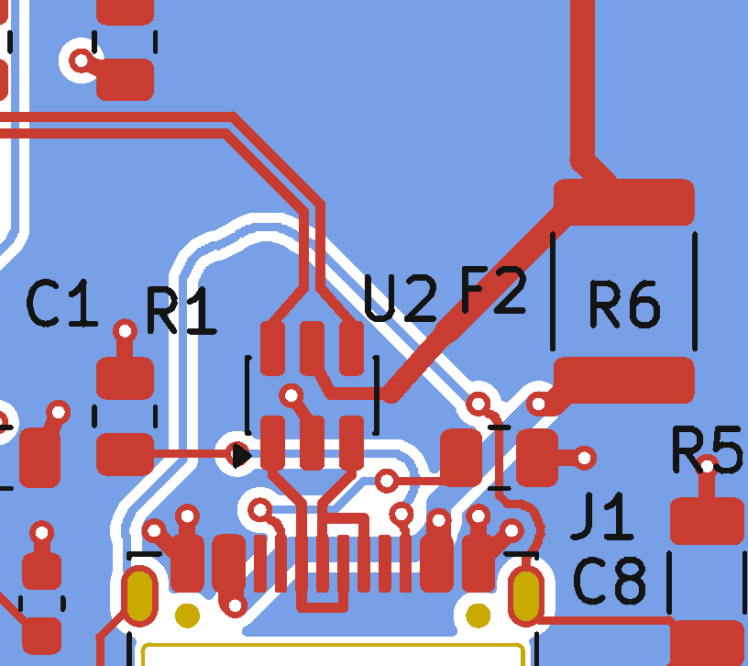
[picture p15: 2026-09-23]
layout/issue8-rules/supply-connector.png

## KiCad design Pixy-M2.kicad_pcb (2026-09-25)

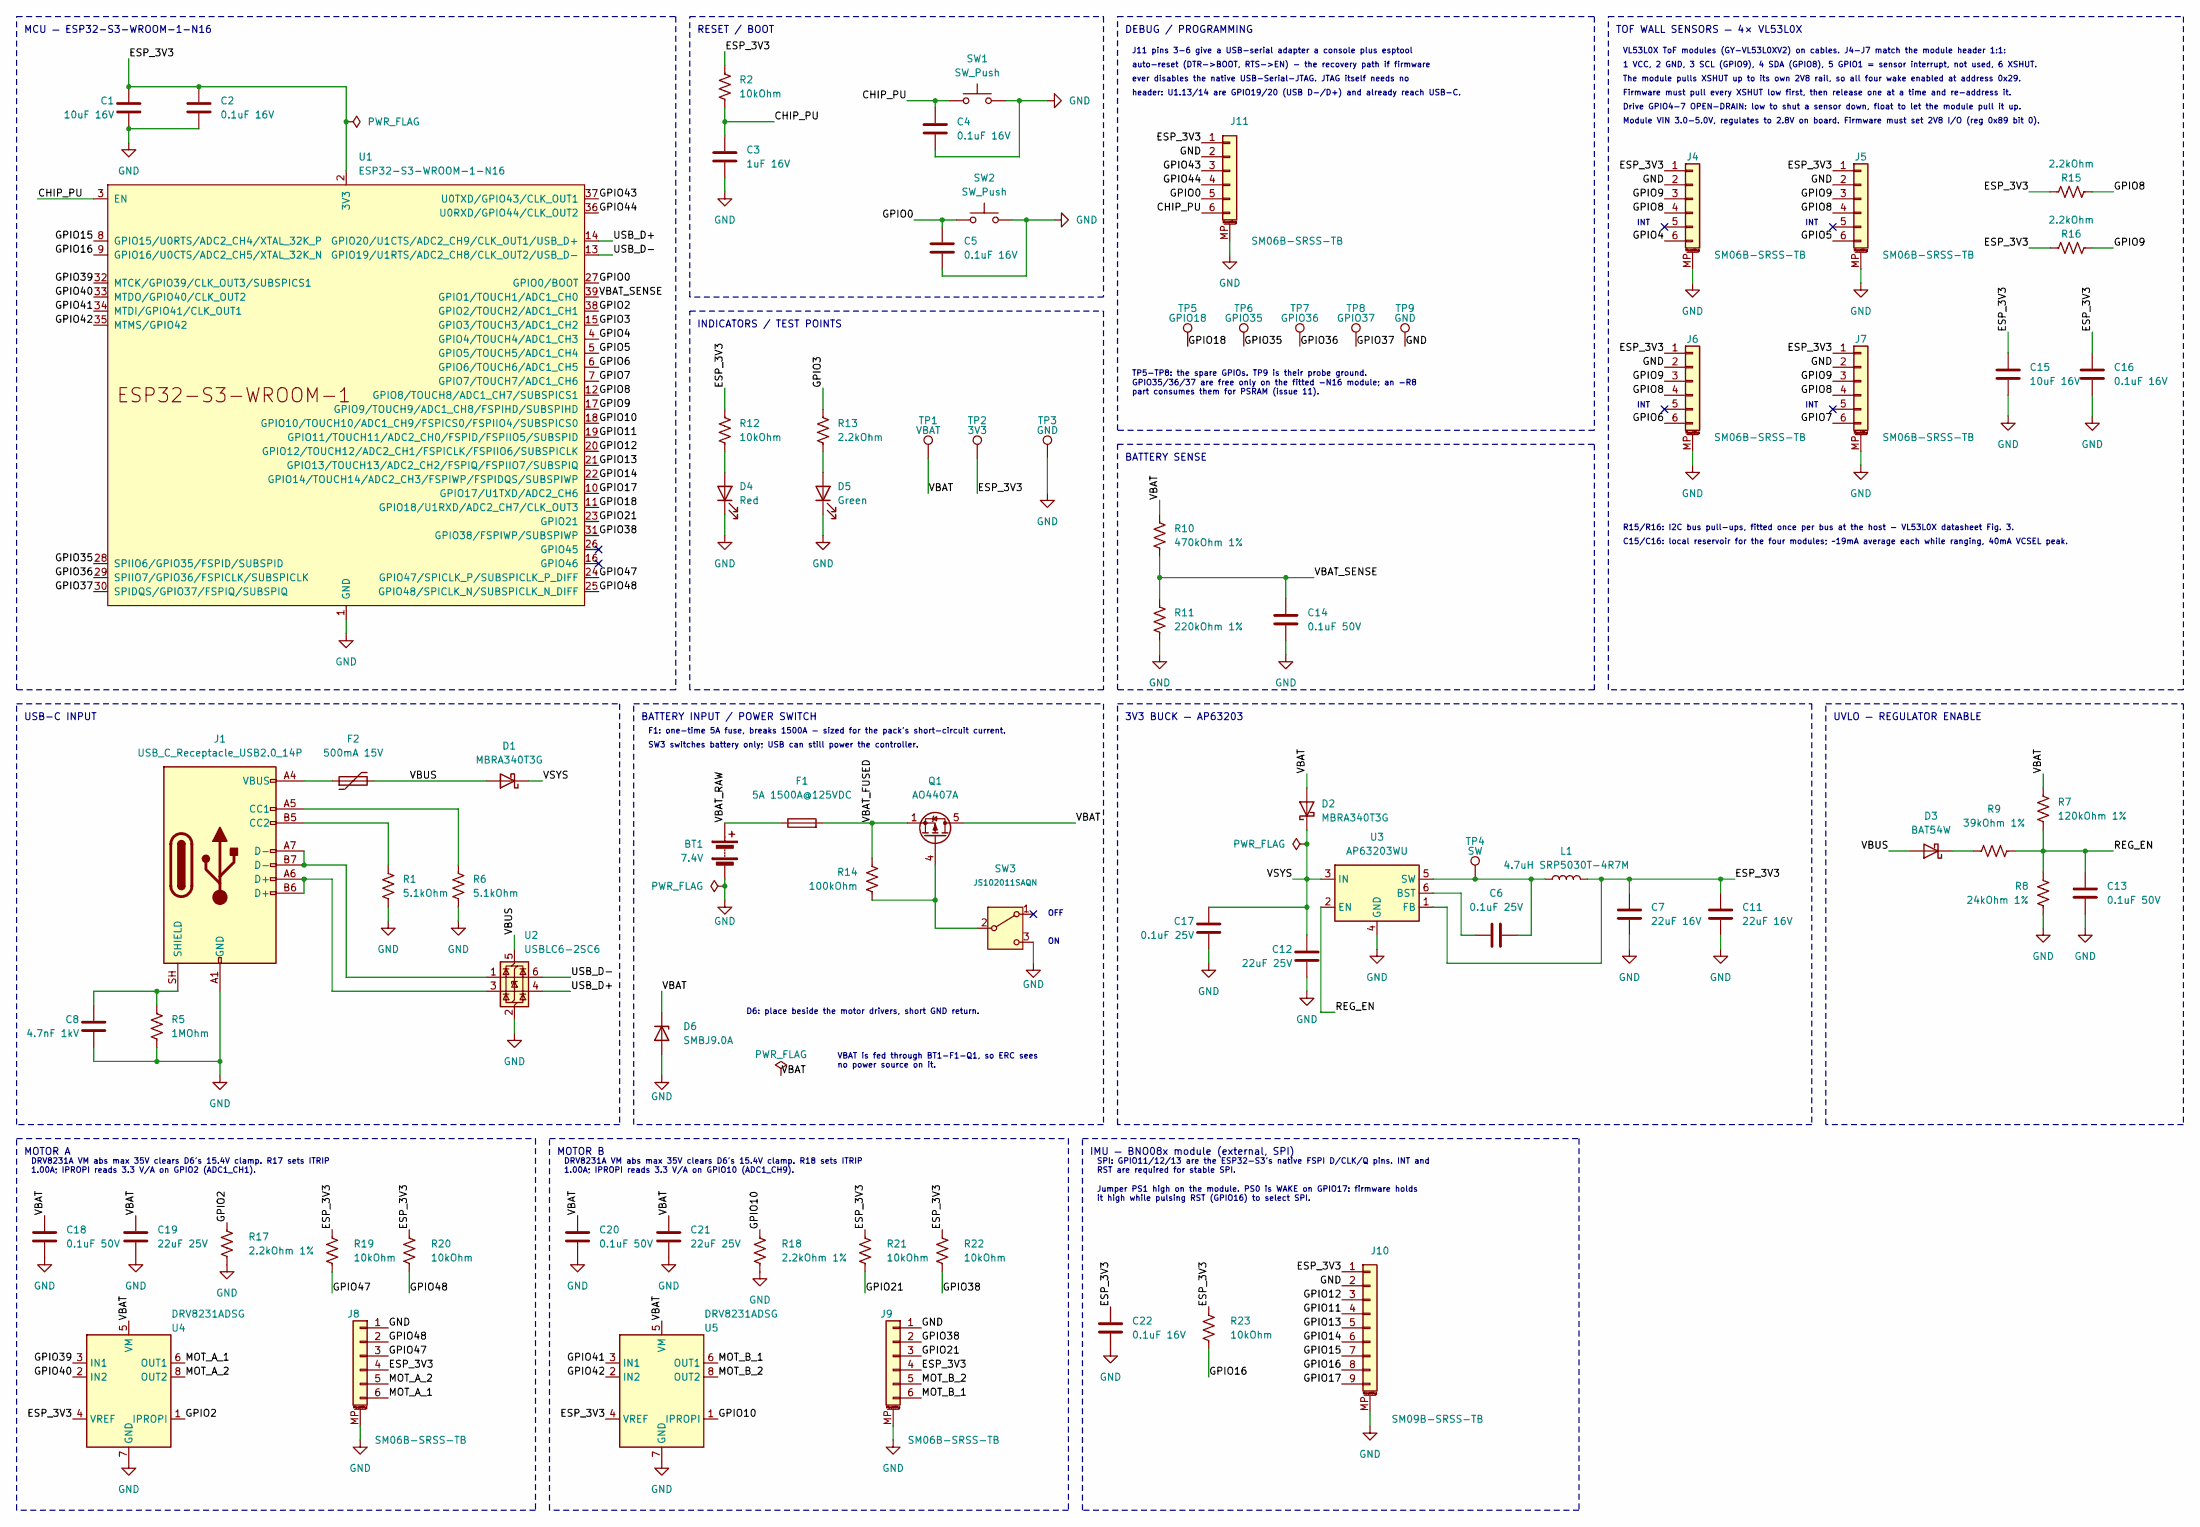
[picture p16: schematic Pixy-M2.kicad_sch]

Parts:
BT1: 7.4V; AMASS_XT30U-M_1x02_P5.0mm_Vertical
C1, C15: 10uF 16V; C_0805_2012Metric
C2, C4, C5, C16, C22: 0.1uF 16V; C_0603_1608Metric
C3: 1uF 16V; C_0603_1608Metric
C6, C17: 0.1uF 25V; C_0603_1608Metric
C7, C11: 22uF 16V; C_0805_2012Metric
C8: 4.7nF 1kV; C_1206_3216Metric
C12, C19, C21: 22uF 25V; C_1206_3216Metric
C13, C14, C18, C20: 0.1uF 50V; C_0603_1608Metric
D1, D2: MBRA340T3G; D_SMA; MPN MBRA340T3G
D3: BAT54W; D_SOD-123
D4: Red; LED_0805_2012Metric
D5: Green; LED_0805_2012Metric
D6: SMBJ9.0A; D_SMB; MPN SMBJ9.0A-E3/52
F1: 5A 1500A@125VDC; Fuse_Littelfuse-NANO2-885; MPN 0885005.DR
F2: 500mA 15V; Fuse_1812_4532Metric; MPN MF-MSMF050-2
J1: USB_C_Receptacle_USB2.0_14P; USB_C_Receptacle_Amphenol_12401948E412A
J4, J5, J6, J7, J8, J9: SM06B-SRSS-TB; JST_SH_SM06B-SRSS-TB_1x06-1MP_P1.00mm_Horizontal; MPN SM06B-SRSS-TB(LF)(SN)
J10: SM09B-SRSS-TB; JST_SH_SM09B-SRSS-TB_1x09-1MP_P1.00mm_Horizontal
J11: SM06B-SRSS-TB; JST_SH_SM06B-SRSS-TB_1x06-1MP_P1.00mm_Horizontal
L1: 4.7uH SRP5030T-4R7M; L_Bourns_SRP5030T; MPN SRP5030T-4R7M
Q1: AO4407A; SOIC-8_3.9x4.9mm_P1.27mm; MPN AO4407A
R1, R6: 5.1kOhm; R_0805_2012Metric
R2, R12, R19, R20, R21, R22, R23: 10kOhm; R_0805_2012Metric
R5: 1MOhm; R_0805_2012Metric
R7: 120kOhm 1%; R_0805_2012Metric
R8: 24kOhm 1%; R_0805_2012Metric
R9: 39kOhm 1%; R_0805_2012Metric
R10: 470kOhm 1%; R_0805_2012Metric
R11: 220kOhm 1%; R_0805_2012Metric
R13, R15, R16: 2.2kOhm; R_0805_2012Metric
R14: 100kOhm; R_0805_2012Metric
R17, R18: 2.2kOhm 1%; R_0805_2012Metric
SW1, SW2: SW_Push; SW_Push_1P1T_NO_E-Switch_TL3301NxxxxxG
SW3: JS102011SAQN; SW_SPDT_CK_JS102011SAQN; MPN JS102011SAQN
TP1: VBAT; TestPoint_Pad_D1.5mm
TP2: 3V3; TestPoint_Pad_D1.5mm
TP3, TP9: GND; TestPoint_Pad_D1.5mm
TP4: SW; TestPoint_Pad_D1.5mm
TP5: GPIO18; TestPoint_Pad_D1.5mm
TP6: GPIO35; TestPoint_Pad_D1.5mm
TP7: GPIO36; TestPoint_Pad_D1.5mm
TP8: GPIO37; TestPoint_Pad_D1.5mm
U1: ESP32-S3-WROOM-1-N16; ESP32-S3-WROOM-1_AntennaOverhang
U2: USBLC6-2SC6; SOT-23-6
U3: AP63203WU; TSOT-23-6
U4, U5: DRV8231ADSG; Texas_DSG0008A_WSON-8-1EP_2x2mm_P0.5mm_EP0.9x1.6mm; MPN DRV8231ADSGR

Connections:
/CHIP_PU: C3.1, C4.2, J11.6, R2.2, SW1.1, U1.3 (EN)
/ESP_3V3: C1.1, C2.1, C7.1, C11.1, C15.1, C16.1, C22.1, J4.1, J5.1, J6.1, J7.1, J8.4, J9.4, J10.1, J11.1, L1.2, R2.1, R12.1, R15.1, R16.1, R19.1, R20.1, R21.1, R22.1, R23.1, TP2.1, U1.2 (3V3), U3.1 (FB), U4.4 (VREF), U5.4 (VREF)
/GPIO0: C5.2, J11.5, SW2.1, U1.27 (GPIO0/BOOT)
/GPIO2: R17.1, U1.38 (GPIO2/TOUCH2/ADC1_CH1), U4.1 (IPROPI)
/GPIO3: R13.1, U1.15 (GPIO3/TOUCH3/ADC1_CH2)
/GPIO4: J4.6, U1.4 (GPIO4/TOUCH4/ADC1_CH3)
/GPIO5: J5.6, U1.5 (GPIO5/TOUCH5/ADC1_CH4)
/GPIO6: J6.6, U1.6 (GPIO6/TOUCH6/ADC1_CH5)
/GPIO7: J7.6, U1.7 (GPIO7/TOUCH7/ADC1_CH6)
/GPIO8: J4.4, J5.4, J6.4, J7.4, R15.2, U1.12 (GPIO8/TOUCH8/ADC1_CH7/SUBSPICS1)
/GPIO9: J4.3, J5.3, J6.3, J7.3, R16.2, U1.17 (GPIO9/TOUCH9/ADC1_CH8/FSPIHD/SUBSPIHD)
/GPIO10: R18.1, U1.18 (GPIO10/TOUCH10/ADC1_CH9/FSPICS0/FSPIIO4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), U5.1 (IPROPI)
/GPIO11: J10.4, U1.19 (GPIO11/TOUCH11/ADC2_CH0/FSPID/FSPIIO5/S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)
/GPIO12: J10.3, U1.20 (GPIO12/TOUCH12/ADC2_CH1/FSPICLK/FSPIIO6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)
/GPIO13: J10.5, U1.21 (GPIO13/TOUCH13/ADC2_CH2/FSPIQ/FSPIIO7/S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)
/GPIO14: J10.6, U1.22 (GPIO14/TOUCH14/ADC2_CH3/FSPIWP/FSPIDQS/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)
/GPIO15: J10.7, U1.8 (GPIO15/U0RTS/ADC2_CH4/XTAL_32K_P)
/GPIO16: J10.8, R23.2, U1.9 (GPIO16/U0CTS/ADC2_CH5/XTAL_32K_N)
/GPIO17: J10.9, U1.10 (GPIO17/U1TXD/ADC2_CH6)
/GPIO18: TP5.1, U1.11 (GPIO18/U1RXD/ADC2_CH7/CLK_OUT3)
/GPIO21: J9.3, R21.2, U1.23 (GPIO21)
/GPIO35: TP6.1, U1.28 (SPIIO6/GPIO35/FSPID/SUBSPID)
/GPIO36: TP7.1, U1.29 (SPIIO7/GPIO36/FSPICLK/SUBSPICLK)
/GPIO37: TP8.1, U1.30 (SPIDQS/GPIO37/FSPIQ/SUBSPIQ)
/GPIO38: J9.2, R22.2, U1.31 (GPIO38/FSPIWP/SUBSPIWP)
/GPIO39: U1.32 (MTCK/GPIO39/CLK_OUT3/SUBSPICS1), U4.3 (IN1)
/GPIO40: U1.33 (MTDO/GPIO40/CLK_OUT2), U4.2 (IN2)
/GPIO41: U1.34 (MTDI/GPIO41/CLK_OUT1), U5.3 (IN1)
/GPIO42: U1.35 (MTMS/GPIO42), U5.2 (IN2)
/GPIO43: J11.3, U1.37 (U0TXD/GPIO43/CLK_OUT1)
/GPIO44: J11.4, U1.36 (U0RXD/GPIO44/CLK_OUT2)
/GPIO47: J8.3, R19.2, U1.24 (GPIO47/SPICLK_P/SUBSPICLK_P_DIFF)
/GPIO48: J8.2, R20.2, U1.25 (GPIO48/SPICLK_N/SUBSPICLK_N_DIFF)
/MOT_A_1: J8.6, U4.6 (OUT1)
/MOT_A_2: J8.5, U4.8 (OUT2)
/MOT_B_1: J9.6, U5.6 (OUT1)
/MOT_B_2: J9.5, U5.8 (OUT2)
/REG_EN: C13.1, R7.2, R8.1, R9.2, U3.2 (EN)
/USB_D+: U1.14 (GPIO20/U1CTS/ADC2_CH9/CLK_OUT1/USB_D+), U2.4 (I/O2)
/USB_D-: U1.13 (GPIO19/U1RTS/ADC2_CH8/CLK_OUT2/USB_D-), U2.6 (I/O1)
/VBAT: C18.1, C19.1, C20.1, C21.1, D2.2 (A), D6.1 (K), Q1.5 (D), Q1.6 (D), Q1.7 (D), Q1.8 (D), R7.1, R10.1, TP1.1, U4.5 (VM), U5.5 (VM)
/VBAT_FUSED: F1.2, Q1.1 (S), Q1.2 (S), Q1.3 (S), R14.1
/VBAT_RAW: BT1.1 (+), F1.1
/VBAT_SENSE: C14.1, R10.2, R11.1, U1.39 (GPIO1/TOUCH1/ADC1_CH0)
/VBUS: D1.2 (A), D3.2 (A), F2.2, U2.5 (VBUS)
/VSYS: C12.1, C17.1, D1.1 (K), D2.1 (K), U3.3 (IN)
GND: BT1.2 (-), C1.2, C2.2, C3.2, C4.1, C5.1, C7.2, C8.2, C11.2, C12.2, C13.2, C14.2, C15.2, C16.2, C17.2, C18.2, C19.2, C20.2, C21.2, C22.2, D4.1 (K), D5.1 (K), D6.2 (A), J1.A1 (GND), J1.A12 (GND), J1.B1 (GND), J1.B12 (GND), J4.2, J4.MP (MountPin), J5.2, J5.MP (MountPin), J6.2, J6.MP (MountPin), J7.2, J7.MP (MountPin), J8.1, J8.MP (MountPin), J9.1, J9.MP (MountPin), J10.2, J10.MP (MountPin), J11.2, J11.MP (MountPin), R1.2, R5.2, R6.2, R8.2, R11.2, R17.2, R18.2, SW1.2, SW2.2, SW3.3 (C), TP3.1, TP9.1, U1.1 (GND), U1.40 (GND), U1.41 (GND), U2.2 (GND), U3.4 (GND), U4.7 (GND), U4.9 (GND), U5.7 (GND), U5.9 (GND)
unnamed: D3.1 (K), R9.1
unnamed: D4.2 (A), R12.2
unnamed: D5.2 (A), R13.2
unnamed: F2.1, J1.A4 (VBUS), J1.A9 (VBUS), J1.B4 (VBUS), J1.B9 (VBUS)
unnamed: J1.A5 (CC1), R6.1
unnamed: J1.B5 (CC2), R1.1
unnamed: J1.A6 (D+), J1.B6 (D+), U2.3 (I/O2)
unnamed: J1.A7 (D-), J1.B7 (D-), U2.1 (I/O1)
unnamed: C8.1, J1.SH (SHIELD), R5.1
unnamed: Q1.4 (G), R14.2, SW3.2 (B)
unnamed: C6.1, U3.6 (BST)
unnamed: C6.2, L1.1, TP4.1, U3.5 (SW)

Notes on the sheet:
OFF
F1: one-time 5A fuse, breaks 1500A - sized for the pack's short-circuit current.
SW3 switches battery only; USB can still power the controller.
D6: place beside the motor drivers, short GND return.
INT
VL53L0X ToF modules (GY-VL53L0XV2) on cables. J4-J7 match the module header 1:1:
1 VCC, 2 GND, 3 SCL (GPIO9), 4 SDA (GPIO8), 5 GPIO1 = sensor interrupt, not used, 6 XSHUT.
The module pulls XSHUT up to its own 2V8 rail, so all four wake enabled at address 0x29.
Firmware must pull every XSHUT low first, then release one at a time and re-address it.
Drive GPIO4-7 OPEN-DRAIN: low to shut a sensor down, float to let the module pull it up.
Module VIN 3.0-5.0V, regulates to 2.8V on board. Firmware must set 2V8 I/O (reg 0x89 bit 0).
R15/R16: I2C bus pull-ups, fitted once per bus at the host - VL53L0X datasheet Fig. 3.
C15/C16: local reservoir for the four modules; ~19mA average each while ranging, 40mA VCSEL peak.
MOTOR A
DRV8231A VM abs max 35V clears D6's 15.4V clamp. R17 sets ITRIP 1.00A; IPROPI reads 3.3 V/A on GPIO2 (ADC1_CH1).
MOTOR B
DRV8231A VM abs max 35V clears D6's 15.4V clamp. R18 sets ITRIP 1.00A; IPROPI reads 3.3 V/A on GPIO10 (ADC1_CH9).
VBAT is fed through BT1-F1-Q1, so ERC sees no power source on it.
IMU — BNO08x module (external, SPI)
SPI: GPIO11/12/13 are the ESP32-S3's native FSPI D/CLK/Q pins. INT and RST are required for stable SPI.
Jumper PS1 high on the module. PS0 is WAKE on GPIO17: firmware holds it high while pulsing RST (GPIO16) to select SPI.
DEBUG / PROGRAMMING
GPIO35/36/37 are free only on the fitted -N16 module; an -R8 part consumes them for PSRAM (issue 11).
J11 pins 3-6 give a USB-serial adapter a console plus esptool
auto-reset (DTR->BOOT, RTS->EN) - the recovery path if firmware
ever disables the native USB-Serial-JTAG. JTAG itself needs no
header: U1.13/14 are GPIO19/20 (USB D-/D+) and already reach USB-C.
TP5-TP8: the spare GPIOs. TP9 is their probe ground.
MCU — ESP32-S3-WROOM-1-N16
RESET / BOOT
INDICATORS / TEST POINTS
BATTERY SENSE
TOF WALL SENSORS — 4× VL53L0X
USB-C INPUT
BATTERY INPUT / POWER SWITCH
3V3 BUCK — AP63203
UVLO — REGULATOR ENABLE

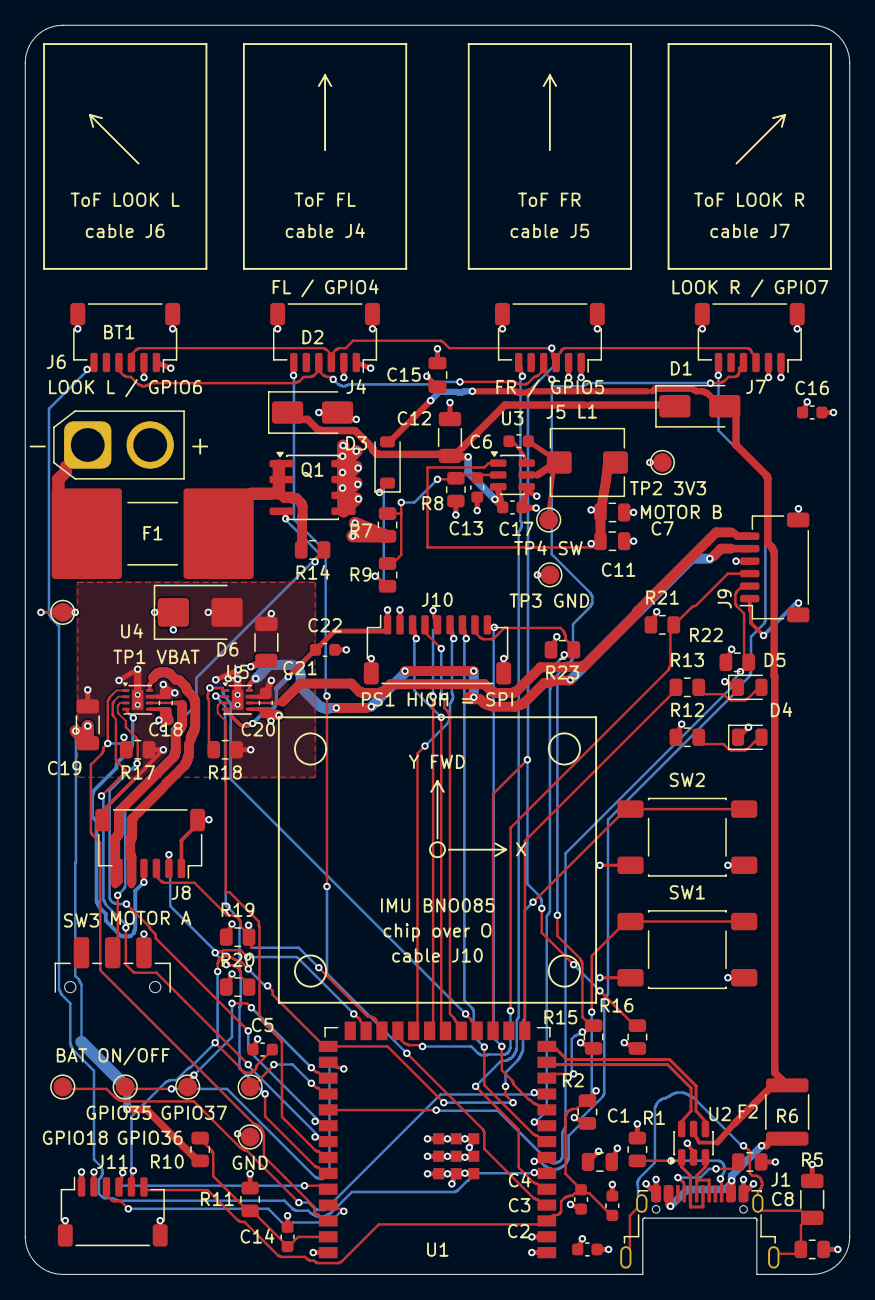
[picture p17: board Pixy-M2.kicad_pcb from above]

Board: 4 copper layers, 66.0 x 100.0 mm, 78 parts (0 on the bottom side), 59 nets.

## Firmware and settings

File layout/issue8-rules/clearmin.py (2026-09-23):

"""Exact minimum copper clearance between net groups, by DRC descent — issue 8.

    python3 layout/issue8-rules/clearmin.py BOARD.kicad_pcb BOARD.kicad_pro [OUT.json]

Method:
run a clearance rule at threshold T; if violated at actual a < T, rerun at a;
stop when nothing violates.  Several starting thresholds are tried and the
smallest result kept: with a large T, DRC reports the first violating shape pair
it meets, not the closest one, and for some pairs reports nothing at all.  The
first attempt at these numbers used a single 20 mm threshold and was wrong by
up to 0.5 mm."""
import json, re, shutil, subprocess, sys, os, tempfile
PAIRS = {
 'REG_EN-SW':      ("A.NetName == '/REG_EN'", "(B.NetName == 'Net-(U3-SW)' || B.NetName == 'Net-(U3-BST)')"),
 'REG_EN-motor':   ("A.NetName == '/REG_EN'", "B.NetClass == 'Motor'"),
 'VBAT_SENSE-SW':  ("A.NetName == '/VBAT_SENSE'", "(B.NetName == 'Net-(U3-SW)' || B.NetName == 'Net-(U3-BST)')"),
 'VBAT_SENSE-motor': ("A.NetName == '/VBAT_SENSE'", "B.NetClass == 'Motor'"),
 'IPROPI-motor':   ("(A.NetName == '/GPIO2' || A.NetName == '/GPIO10')", "B.NetClass == 'Motor'"),
 'USB-other':      ("A.NetClass == 'USB'", "B.NetClass != 'USB'"),
 'VBUS-SW':        ("(A.NetName == '/VBUS' || A.NetName == '/VSYS')", "(B.NetName == 'Net-(U3-SW)' || B.NetName == 'Net-(U3-BST)')"),
}
def run(board, pro, rules):
    d = tempfile.mkdtemp()
    shutil.copy(board, d + '/b.kicad_pcb'); shutil.copy(pro, d + '/b.kicad_pro')
    open(d + '/b.kicad_dru', 'w').write('(version 1)\n' + '\n'.join(rules) + '\n')
    subprocess.run(['kicad-cli', 'pcb', 'drc', '--format', 'json', '-o', d + '/o.json', d + '/b.kicad_pcb'],
                   capture_output=True)
    out = json.load(open(d + '/o.json')); shutil.rmtree(d)
    return out
def measure(board, pro, start=12.0):
    T = {k: start for k in PAIRS}; best = {k: None for k in PAIRS}; live = set(PAIRS)
    while live:
        rules = [f'(rule "M {k}" (constraint clearance (min {T[k]:.4f}mm)) (condition "{a} && {b}"))'
                 for k, (a, b) in PAIRS.items() if k in live]
        d = run(board, pro, rules); hit = {}
        for v in d['violations']:
            m = re.search(r"rule 'M ([^']+)'.*actual ([\d.]+) mm", v['description'])
            if m:
                k, a = m.group(1), float(m.group(2))
                if k not in hit or a < hit[k][0]:
                    hit[k] = (a, [(i['description'][:36], i['pos']['x'], i['pos']['y']) for i in v['items']])
        for k in list(live):
            if k in hit and (best[k] is None or hit[k][0] < best[k][0] - 1e-6):
                best[k] = hit[k]; T[k] = hit[k][0] - 1e-4
            else:
                live.discard(k)
    return best
def measure_all(board, pro, starts=(0.6, 1.2, 2.5, 5.0, 10.0, 20.0)):
    best = {k: None for k in PAIRS}
    for s in starts:
        for k, v in measure(board, pro, s).items():
            if v and (best[k] is None or v[0] < best[k][0]): best[k] = v
    return best
if __name__ == '__main__':
    res = measure_all(sys.argv[1], sys.argv[2])
    for k, v in res.items(): print(f'  {k:18s}', v if v else '> 20 mm')
    if len(sys.argv) > 3: json.dump(res, open(sys.argv[3], 'w'), indent=1)

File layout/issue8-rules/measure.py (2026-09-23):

#!/usr/bin/env python3
"""Issue-8 measurements: per-net track widths, supply-path resistance, and
which nets differ from a reference board.

    python3 layout/issue8-rules/measure.py BEFORE.kicad_pcb AFTER.kicad_pcb [--json OUT]
"""
import collections, heapq, json, math, os, sys
sys.path.insert(0, os.path.join(os.path.dirname(os.path.abspath(__file__)), '..', '..', 'tools', 'autoroute'))
from pcbedit import Pcb
from sexp import parse, children
from load import fp_info

RHO, T_CU = 1.72e-8, 35e-6          # copper at 20 C, 1 oz outer layer
NETS = ['/GPIO2', '/GPIO10', '/GPIO39', '/GPIO40', '/GPIO41', '/VBUS', 'Net-(F2-Pad1)',
        '/VSYS', '/VBAT_RAW', '/VBAT_FUSED']
PATHS = [('USB input, J1.A9 -> F2.1', 'Net-(F2-Pad1)', ('J1', 'A9'), ('F2', '1')),
         ('USB input, J1.A4 -> F2.1', 'Net-(F2-Pad1)', ('J1', 'A4'), ('F2', '1')),
         ('VBUS, F2.2 -> D1.2', '/VBUS', ('F2', '2'), ('D1', '2')),
         ('battery, F1.2 -> Q1 source', '/VBAT_FUSED', ('F1', '2'), ('Q1', '1'))]


def load(path):
    p = Pcb(path); pads = collections.defaultdict(list)
    for f in children(parse(p.text), 'footprint'):
        fi = fp_info(f)
        for q in fi['pads']:
            pads[(fi['ref'], q['num'])].append(q)
    return p, pads


def inside(q, x, y):
    w, h = q['w'], q['h']
    if abs(q['rot'] % 180 - 90) < 1: w, h = h, w
    return abs(x - q['x']) <= w / 2 + 1e-6 and abs(y - q['y']) <= h / 2 + 1e-6


def graph(p, pads, net):
    """copper graph of one net: track endpoints, T-junctions, via barrels,
    overlapping end caps, and every node inside a common pad"""
    adj = collections.defaultdict(list)
    def e(u, v, r): adj[u].append((v, r)); adj[v].append((u, r))
    segs = [Pcb.geom(b) for b in p.blocks if Pcb.net(b) == net and Pcb.kind(b) == 'segment']
    vias = [Pcb.geom(b) for b in p.blocks if Pcb.net(b) == net and Pcb.kind(b) == 'via']
    nodes = set()
    for g in segs:
        u, v = (round(g[0], 3), round(g[1], 3), g[5]), (round(g[2], 3), round(g[3], 3), g[5])
        e(u, v, RHO * math.dist(g[:2], g[2:4]) * 1e-3 / (g[4] * 1e-3 * T_CU)); nodes |= {u, v}
    for g in vias:
        a, b = (round(g[0], 3), round(g[1], 3), 'F.Cu'), (round(g[0], 3), round(g[1], 3), 'B.Cu')
        e(a, b, 0.0); nodes |= {a, b}
    nodes = list(nodes)
    for i, u in enumerate(nodes):
        for v in nodes[i + 1:]:
            if u[2] == v[2] and math.dist(u[:2], v[:2]) < 0.3: e(u, v, 0.0)   # overlapping caps
        for g in segs:
            if g[5] != u[2]: continue
            x1, y1, x2, y2 = g[:4]; dx, dy = x2 - x1, y2 - y1; L2 = dx * dx + dy * dy
            if not L2: continue
            t = max(0, min(1, ((u[0] - x1) * dx + (u[1] - y1) * dy) / L2))
            if 1e-6 < t < 1 - 1e-6 and math.hypot(u[0] - x1 - t * dx, u[1] - y1 - t * dy) < g[4] / 2:
                r = RHO * math.sqrt(L2) * 1e-3 / (g[4] * 1e-3 * T_CU)
                e(u, (round(x1, 3), round(y1, 3), g[5]), r * t); e(u, (round(x2, 3), round(y2, 3), g[5]), r * (1 - t))
    for qs in pads.values():
        for q in qs:
            if q['net'] != net: continue
            inn = [u for u in nodes if (u[2] in q['layers'] or '*.Cu' in q['layers']) and inside(q, *u[:2])]
            for a in inn[1:]: e(inn[0], a, 0.0)
    return adj, nodes


def resistance(p, pads, net, a, b):
    adj, nodes = graph(p, pads, net)
    S = [u for q in pads[a] for u in nodes if (u[2] in q['layers']) and inside(q, *u[:2])]
    T = {u for q in pads[b] for u in nodes if (u[2] in q['layers']) and inside(q, *u[:2])}
    dist, h = {}, [(0.0, s) for s in S]
    for s in S: dist[s] = 0.0
    while h:
        d, u = heapq.heappop(h)
        if u in T: return d
        if d > dist.get(u, 1e9): continue
        for v, r in adj[u]:
            if d + r < dist.get(v, 1e9): dist[v] = d + r; heapq.heappush(h, (d + r, v))
    return None


def widths(p):
    W = collections.defaultdict(collections.Counter)
    for b in p.blocks:
        if Pcb.kind(b) == 'segment':
            g = Pcb.geom(b); W[Pcb.net(b)][g[4]] += math.dist(g[:2], g[2:4])
    return W


def report(path):
    p, pads = load(path); W = widths(p)
    allw = collections.Counter()
    for c in W.values(): allw.update(c)
    return {'widths_mm': {n: {str(w): round(l, 2) for w, l in sorted(W[n].items())} for n in NETS},
            'track_below_0.2mm': round(sum(l for w, l in allw.items() if w < 0.2), 2),
            'path_resistance_mohm': {k: (round(1e3 * r, 1) if (r := resistance(p, pads, n, a, b)) is not None else None)
                                     for k, n, a, b in PATHS},
            'vias': sum(Pcb.kind(b) == 'via' for b in p.blocks)}


def changed_nets(a, b):
    def items(path):
        return {(Pcb.kind(x), Pcb.net(x)) + tuple(round(v, 4) if isinstance(v, float) else v for v in Pcb.geom(x))
                for x in Pcb(path).blocks}
    A, B = items(a), items(b); out = {}
    for tag, S in (('removed', A - B), ('added', B - A)):
        for it in S: out.setdefault(it[1], {'removed': 0, 'added': 0})[tag] += 1
    return out


if __name__ == '__main__':
    res = {'before': report(sys.argv[1]), 'after': report(sys.argv[2]),
           'changed_nets': changed_nets(sys.argv[1], sys.argv[2])}
    txt = json.dumps(res, indent=2)
    if '--json' in sys.argv: open(sys.argv[sys.argv.index('--json') + 1], 'w').write(txt + '\n')
    print(txt)

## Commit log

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2026-09-19 Add undervoltage lockout for the 2S LiPo (open issue 2)
    U3.2 (EN) and U3.3 (IN) were the same net, so the AP63203WU could never turn
    itself off. The ESP32 would keep drawing from the pack until the cells were
    damaged, with the usual LiPo failure modes on the next recharge. EN is now
    driven by a programmed UVLO network, and VSYS carries U3.3 (IN) only.
    VBAT ---[R7 120k]---+--------------- U3.2 (EN) net: REG_EN
    |
    VBUS ---|<|---[R9 39k] D3 = BAT54W
    D3 |
    +---[R8 24k]--- GND
    +---[C13 100nF]--- GND
    New parts: R7 120kOhm 1%, R8 24kOhm 1%, R9 39kOhm 1% (0805),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
    [Pixy-M2.kicad_sch]
2026-09-19 Add battery sense divider into ADC1 (open issue 5)
    VBAT_SENSE was a label on U1.39 and nothing else - a single-pin net - so the
    MCU had no way to read pack voltage. It can now:
    VBAT --[R10 470k]--+--> U1.39 GPIO1 / ADC1_CH0
    [R11 220k] [C14 100nF]
    | |
    GND GND
    New parts: R10 470kOhm 1%, R11 220kOhm 1% (0805), C14 0.1uF 50V (0603).
    This matters because issue 2's hardware UVLO is deliberately defeated whenever
    USB is connected, and its battery-only cutoff carries a +/-0.15 V/cell
    tolerance spread. Firmware is the accurate mechanism and until now it was
    blind. GPIO1 is ADC1_CH0;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
    [Pixy-M2.kicad_sch]
2026-09-19 Add indicator LEDs and test points (open issue 13)
    Power LED: ESP_3V3 -[R12 10k]- D4 (red) -> GND, ~150uA
    Status LED: GPIO3 -[R13 2.2k]- D5 (green) -> GND, ~550uA when lit
    Test points: TP1 VBAT, TP2 3V3, TP3 GND, TP4 SW node
    D4 is red because the specified 10k constrains the colour: at 3.3V a
    10k resistor delivers (3.3 - Vf)/10k, so a pure-green InGaN part
    (Vf ~3.1V) would draw ~10uA and not light. Red (Vf ~1.7-1.9V) gives
    ~150uA. Blue/white/pure-green cannot be substituted without changing
    the resistor.
    D5 sits on GPIO3, the only one of the three floating strapping pins
    that issue 12 found safe to repurpose, and is wired active-high so
    the pin stays at 0V at reset via its internal pu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
    [Pixy-M2.kicad_sch]
2026-09-19 Add battery power switch, input fuses and TVS (issue 7)
    The battery previously fed the regulator and daughterboard directly, with
    no power switch or fuse. The UVLO and battery-sense dividers also remained
    connected to the pack, drawing about 70uA even when the regulator stopped.
    USB VBUS likewise had no board-level fuse, and the shared motor supply had
    no transient clamp.
    Add six components to the schematic:
    - F1: Littelfuse 2920L300/15DR battery PPTC, provisionally 3A hold / 5A trip
    at 20C, rated for 15V, in a 2920 footprint.
    - Q1: AO4407A P-channel MOSFET load switch, with source pins 1-3 connected
    to VBAT_FUSED and drain pins 5-8 connected to the existing VBAT net.
    - R14: 100k gate-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
    [Pixy-M2.kicad_sch]
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2026-09-19 Make L1 value and footprint name the same part (issue 1)
    L1's Value named a Sunlord SWPA4030S4R7MT (4.0x4.0mm) while its Footprint
    was the Bourns SRP5030T land pattern (5.0x5.0mm). The two are not
    interchangeable -- Bourns is 2.0x1.8mm pads on a 4.5mm pitch, Sunlord
    1.1x3.7mm pads on a 3.0mm pitch -- so the part would not have sat on its
    pads. This was the last item blocking layout.
    Settle on the Bourns SRP5030T-4R7M, keeping the footprint already
    assigned, and write Value, MPN, Datasheet and Description together so the
    component cannot go half-updated again. Ratings confirmed against the
    datasheet: 4.7uH +/-20%, DCR 53mOhm max, Irms 4.6A, Isat 6A. Earlier notes
    quoted the 4.6A Irms figure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
    [Pixy-M2.kicad_sch]
2026-09-19 Add VL53L0X ToF sensor connectors (issue 14)
    Wall sensing existed only as an architectural note -- CLAUDE.md said "IR
    emitters/receivers" would live on the daughterboard, and nothing in the
    schematic reflected any sensor at all. Replace that with four VL53L0X
    time-of-flight modules on cables.
    The sensors stay off-board so they can be aimed mechanically at the maze
    walls; this PCB carries only their connectors, the shared bus pull-ups and
    the local rail decoupling. Eight components added:
    - J4-J7: JST SM06B-SRSS-TB, 6-position SH 1.0mm side-entry receptacles,
    one per sensor, with the two MP mounting pegs tied to GND.
    - R15, R16: 2.2k I2C pull-ups on GPIO8 (SDA) and GPIO9 (SCL) to ESP_3V3.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
    [Pixy-M2.kicad_sch]
2026-09-20 Replace daughterboard architecture with single-board 4-layer plan
    Records the 2026-09-20 decision to put motor drivers, encoders and the IMU
    on this PCB rather than on a mezzanine, and to lay it out on 4 layers.
    Architecture:
    - "What this board is" rewritten as single-board; VBAT relabelled the
    motor/high-current supply.
    - Schematic no longer described as complete — only its controller section is.
    - J2/J3 demoted from interface contract to a placeholder parking 29 GPIOs.
    New "Board stackup" section: L1 signal, L2 unbroken GND, L3 VBAT/3V3 pours,
    L4 signal + stitched GND. Never split L2; partition by placement. Antenna
    keep-out must now be cut from four layers including both pours.
    New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
2026-09-20 Flag GPIO45/GPIO46 no-connect (issue 12)
    Both pins were unconnected on U1 with a net label on each, producing the
    two isolated_pin_label ERC warnings. Removed the labels and added explicit
    no-connect flags at U1.26 (GPIO45) and U1.16 (GPIO46).
    This was tidiness, not a fault -- the ESP32-S3's internal weak pulldowns
    already hold both pins at their safe state. What the flags buy is intent:
    an unconnected pin and a pin someone forgot to wire look identical in a
    netlist, and these two must stay unconnected because both are strapping
    pins that are harmful to drive high at reset.
    Explicit 10k pulldowns were considered and rejected; the reasoning is
    recorded in issue 12 so it is not re-litigated.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
    [Pixy-M2.kicad_sch]
2026-09-20 Remove series resistors from USB D+/D- (issue 10)
    R3 and R4 (22 ohm) sat between U2 and the module's USB pins and did
    nothing: the ESP32-S3's USB PHY is internally impedance-matched and
    Espressif's reference designs connect straight through. Deleted both
    symbols and joined the wires so U2 drives U1 directly.
    Deleted rather than set to 0 ohm. Both were sanctioned by the original
    note; removal won because two 0805 jumper pads are a discontinuity in the
    90 ohm differential pair the layout rules call for, sitting exactly where
    routing is tightest next to the USB-C connector. At Full Speed (12 Mbps)
    that discontinuity would have been harmless in practice -- this is about
    keeping the pair clean a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
    [Pixy-M2.kicad_sch]
2026-09-20 Specify real parts for OR-ing diodes D1/D2 (issue 9)
    Both were Value "D_Schottky" with an empty Datasheet field. Both are now
    onsemi MBRA340T3G -- same part in both positions, since the requirements
    and footprint are identical and it saves a BOM line and a reel. Value,
    MPN, Datasheet and Description populated together, following D3/BAT54W.
    Verified against the onsemi datasheet (MBRA340T3/D Rev. 12) rather than
    from memory: SMA / CASE 403D (DO-214AC), VRRM 40V, IO 3.0A at TL = 100C,
    IFSM 100A, VF 0.450V max at 3.0A/25C, IR 0.3mA at 40V/25C, RthJA 81 C/W.
    Corrects this issue's premise, which was wrong. It claimed D2 carries the
    entire system current (~1A, ~400mW) and on that basis floated re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
    [Pixy-M2.kicad_sch]
2026-09-20 Specify capacitor voltage ratings and fix the VSYS input network (issue 8)
    Every capacitor now states its rating in the Value field, following C13's
    precedent so it is visible on the sheet. Ten caps gained one; C13/C14/C15/C16
    already had theirs.
    Two changes go beyond adding text, and both move Value and Footprint
    together rather than leaving a half-updated component:
    C12: 10uF 0805 -> 22uF 25V 1206. Checked against the AP63203 datasheet
    (DS41326 Rev 3-2) rather than this issue's own note, which was wrong: it
    claimed the part wants ~2x10uF effective input capacitance. Table 2 specifies
    C1 (input) = 10uF, and the Input Capacitor section says ">10uF is sufficient
    for most applications". The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
    [Pixy-M2.kicad_sch]
2026-09-20 Record deferred part decisions for issues 15 and 17
    Documentation only -- no schematic change, and nothing from issues 15-17 is
    implemented. Captures three decisions made while deferring them, so the next
    session starts from these rather than re-deriving them:
    - Motors: high-power class, >=3A stall each
    - IMU: dedicated SPI rather than the ToF I2C (~4 GPIOs; free budget 23 -> ~19)
    - Suction fan: planned and fitted
    The motor class has a consequence for hardware already on the board, which is
    the real reason to write this down now: F1 is undersized. It is a 3A-hold /
    5A-trip PPTC whose hold falls to ~2.31A at 60C, against >=6A of stall current
    before fan inrush. A stall against a maze wall w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
2026-09-20 Switch motor class to high-speed N20; reverse the F1 verdict (issues 15, 17)
    Documentation only -- no schematic change. Replaces the "high-power, >=3A
    stall" motor class recorded in e8b7646 with high-speed N20 gearmotors, and
    recomputes everything that was derived from the old figure.
    Reference figures from Pololu's 10:1 HP 6V product page, a representative
    high-speed variant: 3100 RPM free-run at 6V, 100mA free-run, 1.6A stall,
    0.22 kg-cm stall torque. Gear ratio changes speed and torque but not the
    electrical figures, so the power path can be sized before the ratio is fixed.
    F1's verdict is reversed, not merely softened. At 1.6A stall scaling to 2.24A
    per motor on a full 8.4V pack, norma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
2026-09-21 Add on-board N20 motor drive: DRV8231A x2, encoders, connectors (issues 15, 16)
    Implements the motor half of issue 15 and closes issue 16. 14 parts added:
    U4/U5 drivers, C18/C20 VM bypass, C19/C21 bulk, R17/R18 current-sense,
    R19-R22 encoder pull-ups, J8/J9 motor+encoder connectors.
    Driver: TI DRV8231A (DRV8231ADSG, WSON-8 2x2mm). The brief was headroom
    above D6's 15.4V clamp, and that eliminated the obvious candidates: DRV8833
    has an 11.8V absolute maximum and TB6612FNG 15V, both below the clamp.
    DRV8874/DRV8876 (40V, 200mOhm) are better on RDS(on) but have no stock KiCad
    symbol. Verified against the TI datasheet: VM 4.5-33V operating with a 35V
    absolute maximum (2.3x the clamp), 3.7A peak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
    [Pixy-M2.kicad_sch]
2026-09-21 Add external BNO08x IMU on SPI; drop the suction fan (issues 15, 17)
    Adds J10 (SM09B-SRSS-TB, 9-pin JST-SH side-entry), R23 and C22 for an
    off-board BNO08x IMU module -- the same pattern as the ToF sensors: this
    board carries the connector, one pull-up and local decoupling.
    Nine conductors: VIN, GND, SCK, MOSI, MISO, CS, INT, RST, WAKE. INT and
    RST are not optional in SPI mode -- the part signals data-ready on INT and
    the datasheet calls both required for stable SPI, which is why the
    connector is 9-way rather than 6.
    WAKE is pin 9 and is physically the same pin as PS0. PS0/PS1 are sampled
    at reset to pick the protocol (both high = SPI), and PS0 is then repurposed
    as WAKE. Hard-jumpering PS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
    [Pixy-M2.kicad_sch]
2026-09-21 Delete J2/J3; add debug header J11 and spare-GPIO pads TP5-TP9 (issue 15)
    Removes the two 22-pin daughterboard headers and replaces them with a
    6-pin debug header and five test pads. J2/J3 were the de-facto debug
    header -- 44 pins carrying every spare GPIO -- but once the motor, IMU and
    console blocks claimed those signals they carried nothing unique, while
    remaining the heaviest and tallest parts on the board after the module.
    Deleting them is a mass and CG win, which is what a micromouse trades on.
    The precondition was that every GPIO they carried already terminates on a
    real part, and that is why the deletion strands nothing. GPIO43/44 and
    CHIP_PU move to J11; GPIO18/35/36/37 move to tes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
    [Pixy-M2.kicad_sch]
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2026-09-22 tools: make autoroute runnable outside the session that wrote it
    board.py, load.py, check.py and wire.py hard-coded an absolute path into a
    scratchpad directory that no longer exists, so none of them imported at all.
    Resolve the module directory from __file__ instead.
    Adds the two modules the motor-region rework needs:
    pcbedit.py text-level surgery on the .kicad_pcb - add/drop segments and
    vias, move footprints and their text fields, append zones
    grid.py obstacle raster of the *current* board: pads and existing
    tracks, vias and holes, with per-net distance fields
    grid.py is the piece wire.py never had. wire.py accumulated its obstacles in
    memory while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
    [board.py, check.py, grid.py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]
2026-09-22 layout: rework the motor region for review findings 1-3
    REVIEW.md found undersized motor-output copper, a poor heat path out of the
    driver exposed pads, and bypass capacitors too far from VM to close a local
    loop. tools/autoroute/rework.py fixes all three in one reproducible pass over
    base-routed.kicad_pcb, a snapshot of the original routing.
    1. Motor copper. MOT_B_1 carried 38.8 of its 42 mm at 0.15 mm, MOT_B_2 41.3 of
    48 mm. All four nets are now 0.8 mm trunks, with 0.2-0.4 mm only inside the
    drivers' own pin field. The motor-B pair goes 0.267 -> 0.062 ohm, so at the
    DRV8231A's 1.47 A limit 0.393 V / 0.578 W become 0.090 V / 0.133 W. A Motor
    netclass and the new Pixy-M2.kicad_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
    [base-routed.kicad_pcb]
2026-09-22 docs: record the motor-region rework, and correct two claims it disproved
    Adds a "Motor-region rework" section to CLAUDE.md and AGENTS.md with the
    before/after measurements, the constraints that shaped the result, and what was
    deliberately left alone. Rewrites tools/autoroute/README.md to cover rework.py
    and the supporting modules, including the step ordering that matters and the
    "! no neck+via for GND" line that is expected output rather than a failure.
    Puts a status header on REVIEW.md saying which findings are closed.
    Two things this file asserted turned out to be wrong, and both are corrected in
    place rather than quietly dropped:
    "Thermal vias are 2 per driver EP" - there were none i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
2026-09-22 layout: pair the motor-B outputs for review finding 4
    MOT_B_1 ran at y ~ 113 while MOT_B_2 detoured through the regulator at
    y ~ 97-105, so the two were 7.2 mm apart on average and the loop they enclose
    was 423.6 mm2 as first routed (347.9 after the issue 1-3 pass, which widened
    them but did not bring them together).
    rework.py now routes MOT_B_1 first, samples its finished polyline, offsets each
    sample 1.15 mm toward the side MOT_B_2 has to end up on, and routes MOT_B_2
    through those points as waypoints; an unreachable waypoint is skipped rather
    than failing the net.
    first routed after 1-3 now
    enclosed loop area 423.6 mm2 347.9 mm2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
    [Pixy-M2.kicad_pcb]
2026-09-22 layout: rework the buck power stage for review finding 5
    Four complaints, all about the regulator block being spread out rather than
    wrong. Six parts moved and the block hand routed in rework.py's buck_block().
    before after
    SW node copper area 5.17 mm2 3.57 mm2
    SW node on B.Cu 2.55 mm 0 mm
    SW node vias 2 0
    C6 (BST) pad to U3.6 4.15 mm 2.25 mm
    U3.4 return via to C17's 5.88 mm 0.95 mm
    L1.2 to C11.1 through copper none 6.95 mm on F.Cu
    C7.1 to C11.1 4.00 mm 2.30 mm
    FB / 3V3 copper to SW or BST 0.27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
    [Pixy-M2.kicad_pcb]
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2026-09-22 layout: shorten GPIO48 encoder route for audit P3
    [Pixy-M2.kicad_pcb]
2026-09-23 layout: complete issue 6 drill clearance and thermal via treatment
    [Pixy-M2.kicad_pcb, via-moves.csv]
2026-09-23 docs: add the 2026-09-22 audit of review fixes 1-6
    Independent audit of the findings 1-6 rework at 86f2628: issue 6 incomplete
    (drill-edge overlaps), the USB D- regression from the via pass, and the
    GPIO48 encoder detour (P3). Evidence: DRC, pad-hole measurements, figures.
    Issue 6 and P3 were addressed in 7a22d06 and 0c70856; the USB regression is
    addressed with review finding 7.
    Claude-Session: https://claude.ai/code/session_01MLrob72MX5PcwtzVMbc3bs
    [motor-width-negative-test.json, overlapping-holes.csv]
2026-09-23 layout: route USB as a coupled pair for review finding 7
    D+/D- were ordinary 0.2 mm traces with varying separation, a D+ detour round
    U2 and asymmetric layer changes; the issue-6 via pass had left the connector
    side D- with 4 vias and 8 mm on B.Cu. Both polarities now run as one pair,
    J1 -> U2 -> U1, entirely on F.Cu over the In1 plane, with no vias.
    USB vias / B.Cu copper 4 / 8.01 mm 0 / 0
    width, module-side gap 0.20, 0.25-0.35 0.25, 0.15 mm
    J1->U2->U1 path, D+ / D- 24.54 / 32.62 20.15 / 19.11 mm
    end-to-end skew 8.08 mm 1.04 mm (~6 ps)
    U2 GND pin to plane via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
    [Pixy-M2.kicad_pcb]
2026-09-23 layout: encode the routing requirements as rules for review finding 8
    The project rules let narrow copper pass anywhere: one Default netclass and a
    0.15 mm global minimum. Findings 1 and 7 added the Motor and USB rules; this
    adds the rest, and fixes the copper the new rules caught.
    Rules:
    Battery netclass (/VBAT_RAW, /VBAT_FUSED) 1.0 mm, DRC floor 0.8 mm
    Power netclass (/VBUS, /VSYS, Net-(F2-Pad1)) 0.6 mm, floor 0.5 mm, except
    U2's VBUS pin under the package ('Power pin escape' area)
    every track >= 0.2 mm except in the DRV8231A pin fields
    clearance floors: REG_EN to SW/BST 0.35 mm; REG_EN and VBAT_SENSE to motor
    copper (and VBAT_SENSE to SW) 5 mm; IPROPI to motor copper 0.25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
    [Pixy-M2.kicad_pcb]
2026-09-23 layout: clear the J1 hole-clearance errors and the U1 footprint warning
    The five DRC items carried since placement are resolved without changing any
    copper, footprint geometry or placement. DRC: 0 violations, 0 unconnected,
    0 schematic parity issues. ERC stays 0.
    J1: the stock Amphenol 12401948E412A footprint puts its GND pads 0.25 mm from
    its own 0.6 mm locating holes - the land pattern KiCad's librarians merged
    against Amphenol drawing c12401948 (kicad-footprints MR !3540). JLCPCB states
    0.20 mm NPTH-to-track. The land pattern stays. Board-setup hole clearance is
    absolute (custom rules cannot relax it), so it goes 0.30 -> 0.20 mm and a new
    "Hole clearance" rule restores 0.30 mm for every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
    [Pixy-M2.kicad_pcb, Pixy-M2.kicad_sch]
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2026-09-23 layout: replace F1 with a fuse that breaks the pack's short-circuit current
    The chosen pack (OVONIC 2S 450 mAh 100C, XT30) is estimated to put 200-400 A
    into a dead short (8-15 mOhm/cell plus connectors, lead, fuse and copper; Ovonic
    publishes no internal resistance). The 2920L300/15DR PPTC was rated to break
    40 A. A lower-C pack was rejected to keep burst current for the motors, and the
    451/453 NANO2 parts (300-400 A @ 32 VDC) sit inside the estimate.
    F1 is now a Littelfuse 0885005.DR: 5 A fast-acting, 1500 A @ 125 VDC breaking,
    11.9 mOhm. 5 A covers the ~2.4 A worst normal load (both motors at the 1.00 A
    limit plus the buck) after the 25% derating. It is one-time: jams are handled
    by the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
    [Pixy-M2.kicad_pcb, Pixy-M2.kicad_sch]
2026-09-23 layout: print where the ToF sensors, IMU and motors attach
    The mechanical reservations were only on Dwgs.User and User.1/2, which are
    not fabricated. assembly_marks.py puts them on the silkscreen:
    - F.SilkS: four ToF mount outlines with aim arrows and their connectors
    (J6/J4/J5/J7), and the Adafruit BNO085 outline, holes, chip centre on the
    rotation centre and X/Y axes (+Y forward).
    - B.SilkS: both Pololu N20 bodies (gearbox 9 / motor 15 / encoder 8 mm) on
    their wheel axles, motor A left -> J8, motor B right -> J9.
    C20 and R15 reference fields move clear of the IMU outline. rework.py runs
    the stage after f1_fuse.py. DRC 0 violations, 0 unconnected, 0 parity;
    aperture audit passes; tr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
    [Pixy-M2.kicad_pcb]
2026-09-23 project: save netclasses in KiCad's sorted order
    KiCad rewrote the netclass list as Default, Battery, Motor, Power, USB
    when it saved the project. The order is the only change: every class's
    width, clearance, gap, priority and pattern is identical.
    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
2026-09-24 schematic: correct three stale sheet notes
    - F1 is no longer provisional: it is the 0885005.DR one-time fuse, sized
    to break the pack's short-circuit current, and there is no fan.
    - D6 goes beside the motor drivers; J2 was deleted on 2026-09-20.
    - The IMU note implied both PS0 and PS1 are module jumpers. Only PS1 is;
    PS0 is WAKE on GPIO17, held high by firmware while RST is pulsed.
    Text only: the netlist is byte-identical and ERC is 0. The README's
    schematic render is regenerated to match.
    [Pixy-M2.kicad_sch]
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2026-09-24 schematic: re-lay out the sheet into framed blocks
    Layout only. Every wire-connected cluster moved rigidly into one of 13
    dashed, titled frames in three rows: MCU, reset/boot, indicators/test
    points, debug, battery sense, ToF; USB-C, battery input, 3V3 buck, UVLO;
    motor A, motor B, IMU. The empty bottom band and right-centre of the A3
    sheet are now used.
    Two blocks were redrawn inside:
    - USB: the CC resistors drop to GND without crossing D+/D-, the pair
    steps down to a lowered U2, and U2 takes VBUS by label.
    - UVLO: the divider reaches U3.2 through its existing REG_EN label
    instead of a wire under the buck, so the blocks can sit apart.
    Also fixed text overlaps: C1/C2, C7/C11, C8/R5 and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
    [Pixy-M2.kicad_sch]
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2026-09-25 layout: move R8/C13 beside U3.2 and take REG_EN out from under U3
    REG_EN is a ~20 kOhm node 1.2 V above the EN comparator threshold, and
    the layout rule was to put R8 and C13 next to U3.2. The issue-5 FB trace
    ran down U3's west side, so EN could only leave through a via under the
    package, 0.40 mm from the SW pin. R8 and C13 sat 7.35 and 9.9 mm of
    copper away.
    C13 and R8 now stand in a row just west of U3, and EN -> C13.1 -> R8.1
    is one straight top-layer run (1.91 / 3.66 mm of copper). FB keeps its
    via-free top-layer sense to C11 and turns south round the outside of the
    new parts. A via on FB would bond it to the In2 3V3 pour beside U3,
    which is what review finding 5 removed. REG_EN's long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
    [Pixy-M2.kicad_pcb]
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2026-09-25 docs: compact CLAUDE.md and AGENTS.md to the working rules
    The notes had grown to 146 KB of issue-by-issue history, much of it
    superseded (J2/J3, the fan, the PPTC F1, the 1.47 A limit). Keep only the
    invariants, do-not rules, checks and KiCad/router traps; the narrative stays
    in git history and the measurements under layout/.
    Re-extracted the netlist while compacting. Corrects the CC resistors
    (R6 on CC1, R1 on CC2), IPROPI scale (3.3 V/A), and records three
    silkscreen labels not yet on the board. README and BOM pointers to removed
    CLAUDE.md sections now point to layout/ and the git log.
2026-10-14 U1: plug-in ESP32-S3-DevKitC-1-N8R8 on SMD sockets, same 66 x 100 mm board
    Replace the soldered WROOM-1 module with an Espressif ESP32-S3-DevKitC-1-N8R8
    (v1.1) on two 1x22 2.54 mm SMD female headers, and remove what the devkit
    carries itself. The outline stays 66 x 100 mm for the diagonal runs.
    Schematic (tools/schematic/devkit.py):
    - U1 -> PCM_Espressif:ESP32-S3-DevKitC on Pixy-M2:ESP32-S3-DevKitC-1_SMD_Sockets;
    Value, Footprint, Datasheet and MPN changed together.
    - 21 parts removed: the USB-C input (J1, U2, F2, R1, R5, R6, C8), the USB
    supply path (D1, D3, R9), reset/boot (R2, C3-C5, SW1, SW2), J11 and TP5-TP8.
    - The AP63203 feeds the devkit's 3V3 pins; its 5V pin is unused.
    - Encode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
